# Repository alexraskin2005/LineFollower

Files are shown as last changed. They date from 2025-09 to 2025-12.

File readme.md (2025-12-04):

# LineFollower

Line follower project op HoGent

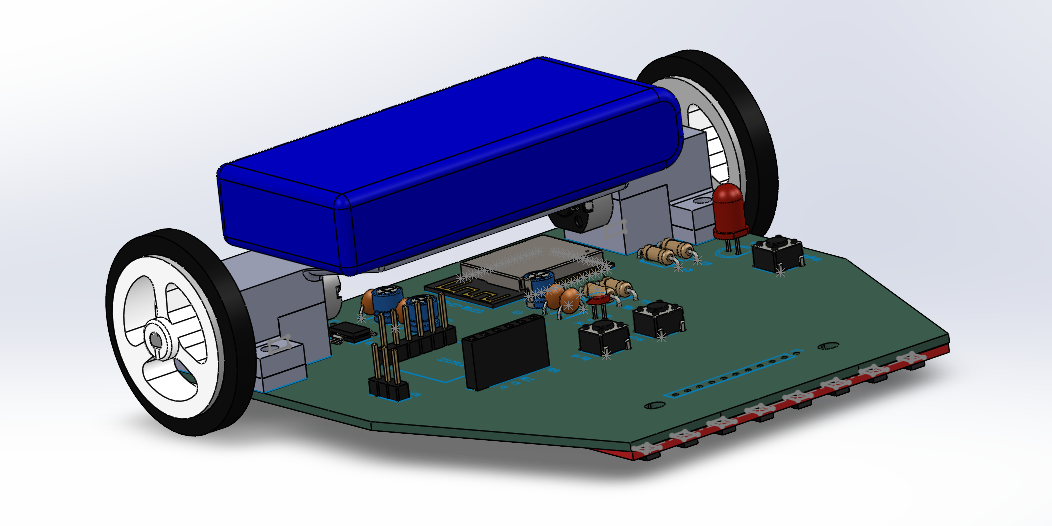
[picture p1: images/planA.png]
A description of my image


## specifications

microcontroller: ESP32

motors: N20 6V 1000RPM

h-bridge: DRV8833

sensors: QTR-8A (fake version)

batteries: lipo 2s 1000mah 20C

wireless communication: ESP32

distance sensor - motors: +-9cm

speed: 0.66 m/s

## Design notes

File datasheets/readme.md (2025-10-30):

# datasheets of the components used in this project

## ESP-WROOM-32:
  datasheet IC:
      https://www.alldatasheet.com/datasheet-pdf/view/1179101/ESPRESSIF/ESP-WROOM-32.html
  
## 8 Channel line tracking sensor:
  geen data sheet maar wel info op product pagina:
      https://nl.aliexpress.com/item/1005007315688221.html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

## GA12-N20 Metal Gear Motor:
  https://www.phippselectronics.com/support/ga12-n20-metal-geared-motor-specifications/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

## DRV8833 motordriver module:
  product page (board): 
      https://nl.aliexpress.com/item/1005006782141292.html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
      
  datasheet IC: 
      https://www.ti.com/lit/ds/symlink/drv8833.pdf?ts=1759987157796
      
  datasheet module:
      https://components101.com/modules/drv8833-dual-h-bridge-motor-driver-module

  ## Turnigy 1000mAh 2S 20C LiPoly Pack:
  product page:
    https://hobbyking.com/en_us/turnigy-1000mah-2s-20c-lipo-pack.html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

  ##  AMS1117:
  https://www.alldatasheet.com/datasheet-pdf/view/49118/ADMOS/AMS1117.html

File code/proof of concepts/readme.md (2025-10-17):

# Proof of Concepts

De proof of concept bestaat uit 1 programma wegens ik verder heb gewerkt op de zelfde fille en vergeten ben apparte filles te maken.
<br />  
<br />
Deze proof of concept heeft de volgende functionaliteit:
* Verbinden via wifi, indien de credentials uit het eeprom niet werken wordt er een configure portal opgezet om deze in te kunnen geven (esp32 in router mode)
* Eenmaal verbonden met wifi kan met linefollwer.local/set?m1= of /set?m2= de pwm output voor de motoren ingesteld worden
* Met linefollwer.local/start of /stop kunnen de motoren gestart en gestopt worden
* Met linefollwer.local/debug kunnen parameters uitgelezen worden, hiermee kunnen de sensor waarden bekeken worden
<br />

<br />
Hiermeer worden de volgende zaken aangetoond:
* De draadloze communicatie werkt
* De motoren kunnen afzonderlijk aangestuurd worden
* De sensoren kunnen uitgelezen worden (hier mee ook te zien dat verschil tussen zwart en wit duidelijk is)
<br />
<br />
  
De elektronische schakelingen van de proof of concepts komt overeen met het elektrisch schema van plan B

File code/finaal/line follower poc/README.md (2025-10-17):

ESP32 WiFi service

What I added

- src/wifi_service.h / src/wifi_service.cpp: a simple WiFi service that:
  - loads/stores Wifi credentials in EEPROM using EEPROMAnything (via PlatformIO lib_deps)
  - attempts to connect to WiFi on startup
  - if connection fails, starts an AP named "ESP32_Config" and serves a minimal HTML form to enter SSID and password
  - saves credentials and restarts
- src/main.cpp updated to initialize the service and print status to Serial
- platformio.ini: added lib_deps = EEPROMAnything
 - src/storage.h: centralized EEPROM storage helper for all project parameters (WiFi credentials start at address 0)

How it works

- Stored credentials are read using the `Storage` helper. WiFi credentials use `STORAGE_WIFI_CRED_ADDR` (0) by default. If SSID is empty the service assumes no credentials are present.
- On first boot, or if connection fails within 15 seconds, the device creates an open AP (password "configureme") and serves a tiny web page at http://192.168.4.1/ where you can enter SSID and password.
- After submitting the form the device saves credentials to EEPROM and restarts.

Assumptions and notes

- Uses Arduino ESP32 core WiFi and WebServer. These are provided by the `espressif32` PlatformIO platform.
- The project cannot be built in this environment (PlatformIO not available here). Build and upload on your machine using PlatformIO in VSCode or the CLI.
- The Storage helper uses `EEPROM.put`/`EEPROM.get` (and `EEPROM.commit`). The `EEPROMAnything` library is declared in `platformio.ini` so PlatformIO will fetch it.

How to build locally (Windows PowerShell)

# Install PlatformIO (if not installed)
# Follow PlatformIO installation instructions for VSCode or CLI: https://platformio.org/install/cli

# From project root:
platformio run
platformio run -t upload

Troubleshooting

- If AP page doesn't load, check Serial output for messages and try connecting to WiFi network named "ESP32_Config".
- The configuration portal runs for 5 minutes; if you miss it, power-cycle the board.

Next improvements

- Use WiFiManager or AsyncWebServer for a more robust captive portal (recommended)
- Encrypt stored password or use Preferences (non-EEPROM) API
- Add captive portal DNS to redirect any URL to the portal

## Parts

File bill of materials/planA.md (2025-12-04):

## bill of materials
<br />

|volgnummer|naam|omschrijving|nieuw/recup|kostprijs/stuk|aantal|subtotaal|
|---|----|---|---|---|---|---|
|1|ESP32-S3-WROOM-1|microcontroller|nieuw|  | 1 | 3.83 |
|2|AMS1117|voltage regulator|nieuw|  | 1 | 1.45 |
|3|DRV8833 module | 2 channel DC motordriver | recup | | 1 |
|4| 8 channel IR line tracking sensor | chinese versie van QTR-8A | recup || 1 | 
|5|ZJ327 3PI 34*7 | rubbere wieltjes voor N20 motors | recup | | 1 |
|6|Turnigy 1000mAh 2S 20C LiPoly Pack| baterij | recup | |1|
|7 | 2-3s LiPoly Charger | lader | recup | |1|
|8| Condensator 10uF | ontkoppeling | recup | | 3 |
|9| Condensator 0u1F | ontkoppeling | recup | | 3 |
|10|weerstand 10k ohm | pullup | recup | | 1 |
|11|weerstand 100 ohm | voorschakel led | recup | | 2 |
|12| led rood (klein) | power led | recup | | 1 |
| 13| FT232RL | usb to ttl | new | | 1 |1.69 |
| 14 | pin header female 6P | pin connector | new | | 1 | 2.46 |
| 15 | led groen | wifi status | recup | | 1
| 16 | push button | start enable en boot| recup ||3

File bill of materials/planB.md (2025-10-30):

## bill of materials
(Mechanische componenten nog niet inclusief)
<br />

|volgnummer|naam|omschrijving|nieuw/recup|kostprijs/stuk|aantal|subtotaal|
|---|----|---|---|---|---|---|
| 1| ESP32-WROOM-32 dev board | microcontroller | nieuw | 0,86 (sale) | 1 | 0,86 |
|2| 8 channel IR line tracking sensor | chinese versie van QTR-8A | nieuw | 2,01 | 1 | 2,01 |
|3| 8 channel IR line tracking sensor | andere fabricant (kon maar 1 per klant bestellen) | nieuw | 1,99 | 1 | 1,99 |
|4|GA12-N20 6VDC 1000RPM | geared motor | nieuw | 3,94 | 2 | 7,88 |
|5|DRV8833 module | 2 channel DC motordriver | nieuw | per 10 verkocht | 10 | 3,24 |
|6|ZJ327 3PI 34*7 | rubbere wieltjes voor N20 motors | nieuw | 1,40 | 2 | 2,80 |
|7|Turnigy 1000mAh 2S 20C LiPoly Pack| baterij | nieuw | 6,04 | 1 | 6,04 |
|8 | 2-3s LiPoly Charger | lader | recup | 0 | 1 | 0 |

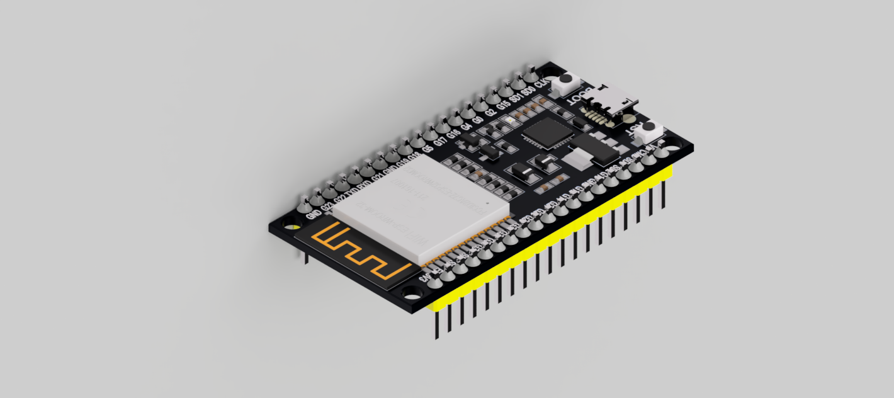
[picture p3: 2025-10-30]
technische tekeningen/mechanisch/parts/esp32-wroom32-devboard/ESP32-WROOM-32_4.png

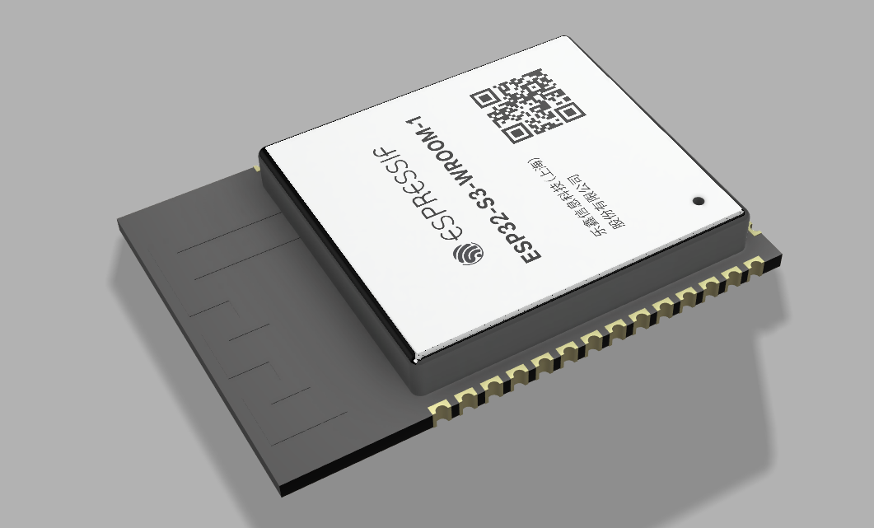
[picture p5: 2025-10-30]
technische tekeningen/mechanisch/parts/esp32-s3-wroom-1/QQ截图20210924173026.png

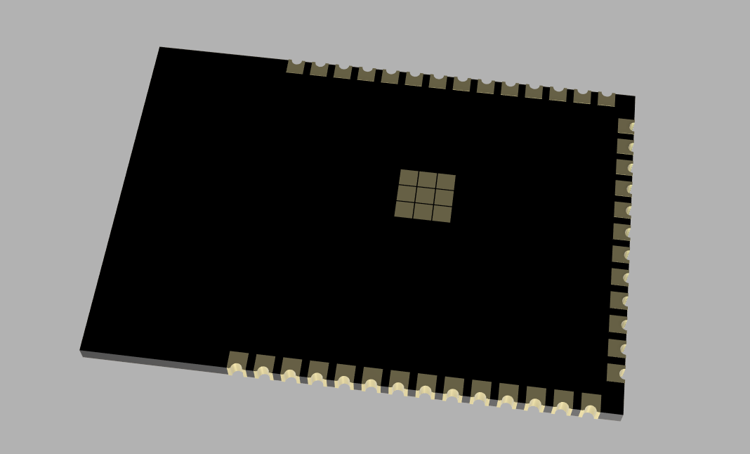
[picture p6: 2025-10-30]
technische tekeningen/mechanisch/parts/esp32-s3-wroom-1/QQ截图20210924175035.png

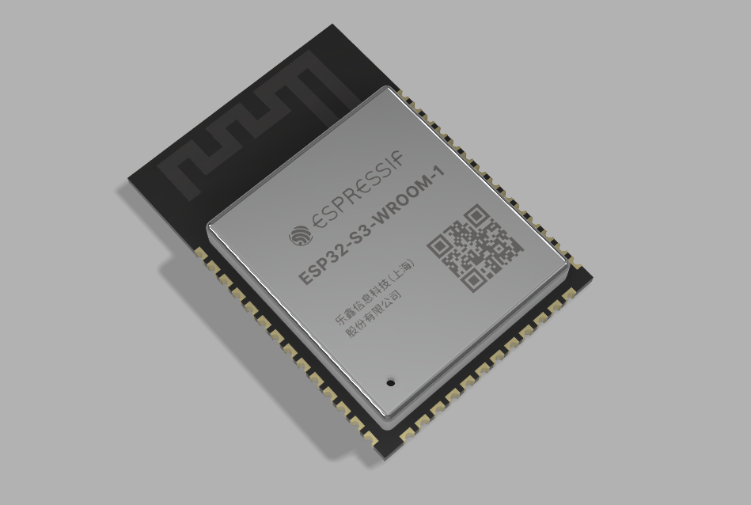
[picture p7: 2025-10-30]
technische tekeningen/mechanisch/parts/esp32-s3-wroom-1/QQ截图20210924200240.png

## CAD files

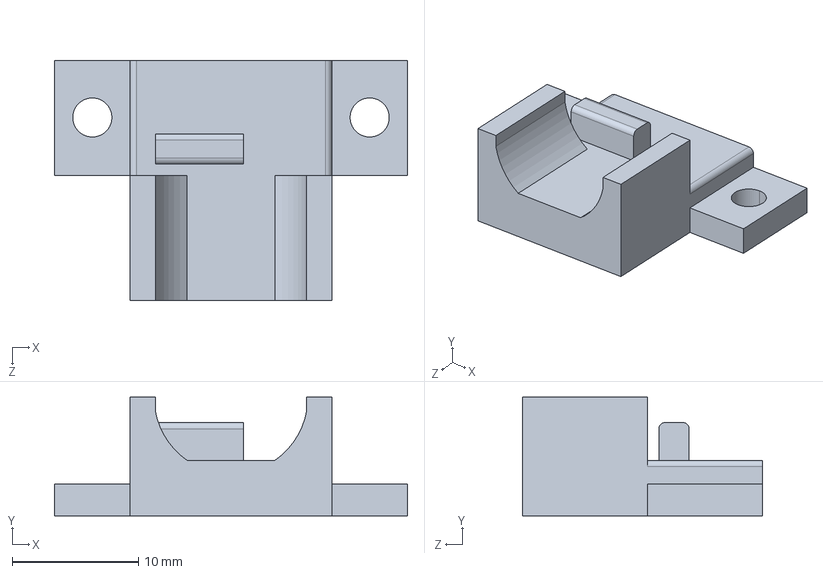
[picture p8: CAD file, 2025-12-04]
technische tekeningen/mechanisch/parts/3D print/n20_holder19_11.STEP
28.0 x 9.40 x 19.0 mm

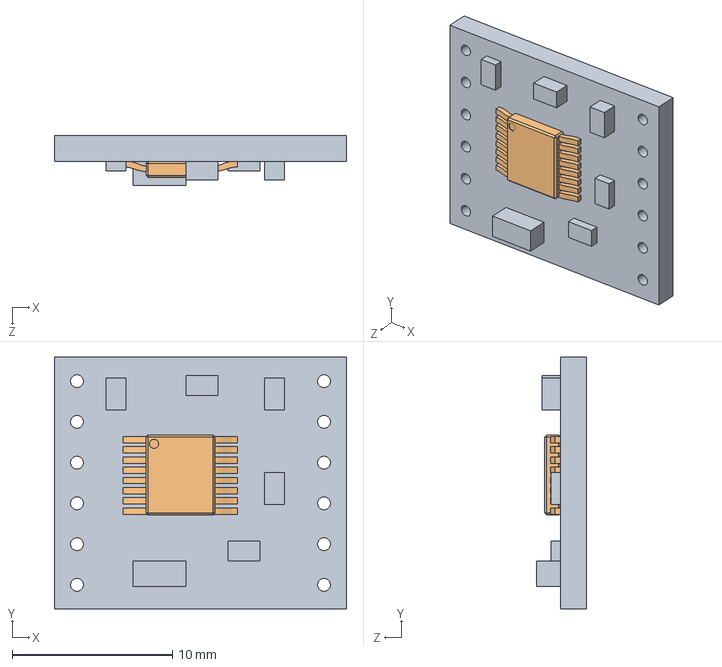
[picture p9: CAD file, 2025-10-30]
technische tekeningen/mechanisch/parts/drv8833-carrier-breakout-board-1/DRV8833.STEP
18.2 x 15.7 x 3.10 mm

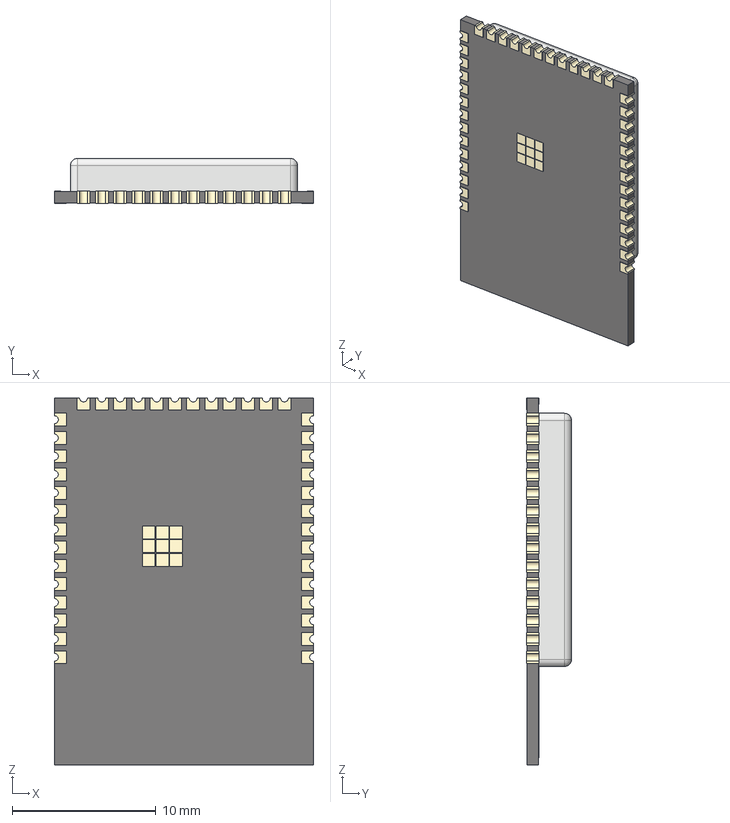
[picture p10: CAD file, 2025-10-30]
technische tekeningen/mechanisch/parts/esp32-s3-wroom-1/ESP32-S3-WROOM.step
18.0 x 3.16 x 25.5 mm
ESP-S3-WROOM_via x 26
ESP32-S3-WROOM_shell
ESP32-S3-WROOM_body
ESP-S3-WROOM_via v3(镜像) x 14

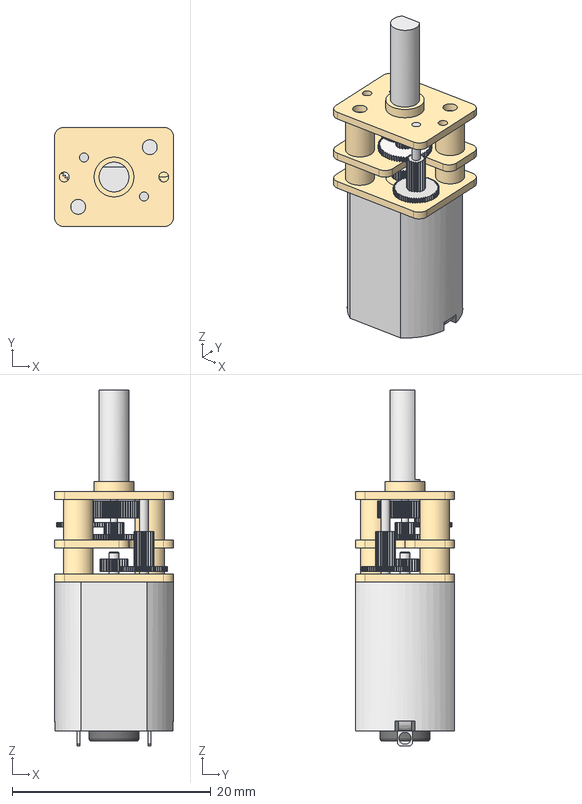
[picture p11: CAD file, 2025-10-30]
technische tekeningen/mechanisch/parts/N20 DC Gear Motor/N20 DC Gear Motor.step
12.0 x 10.0 x 35.8 mm
Gear Box
Shaft
Motor

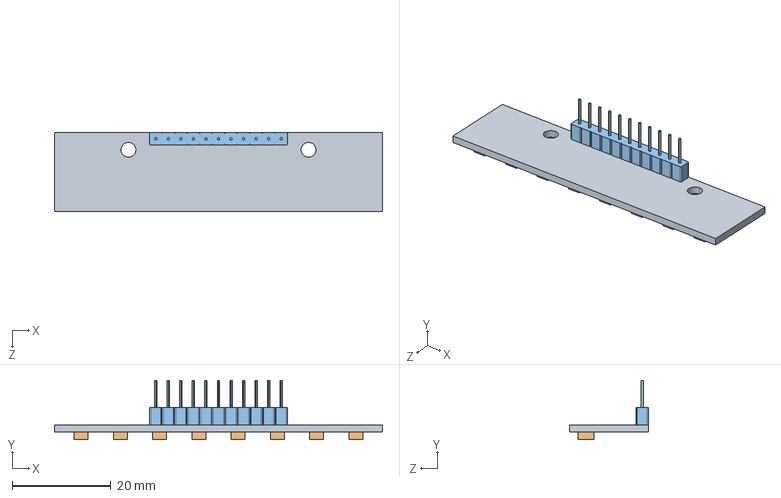
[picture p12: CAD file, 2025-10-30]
technische tekeningen/mechanisch/parts/qtr-8-1.snapshot.2/Qtr-8 IR Array.STEP
66.5 x 12.0 x 16.0 mm

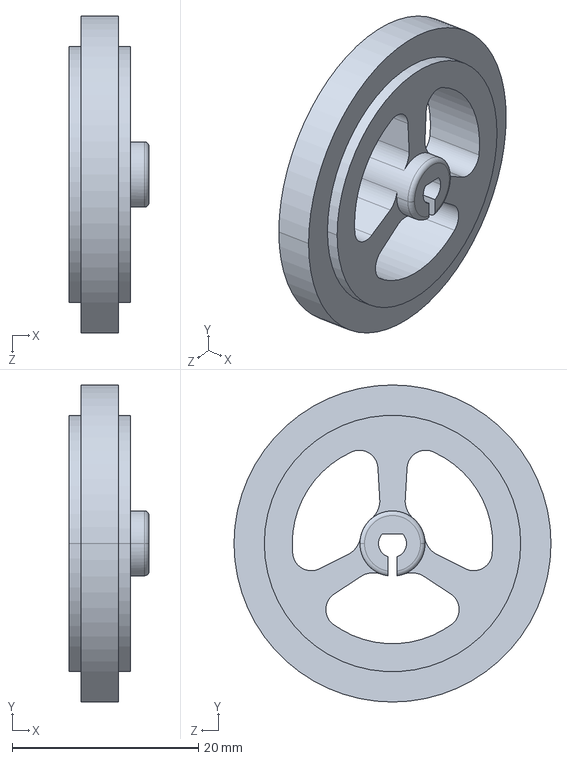
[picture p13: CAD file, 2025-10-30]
technische tekeningen/mechanisch/parts/wheel-34mm/Wheel 34 mm.STEP
8.60 x 34.0 x 34.0 mm

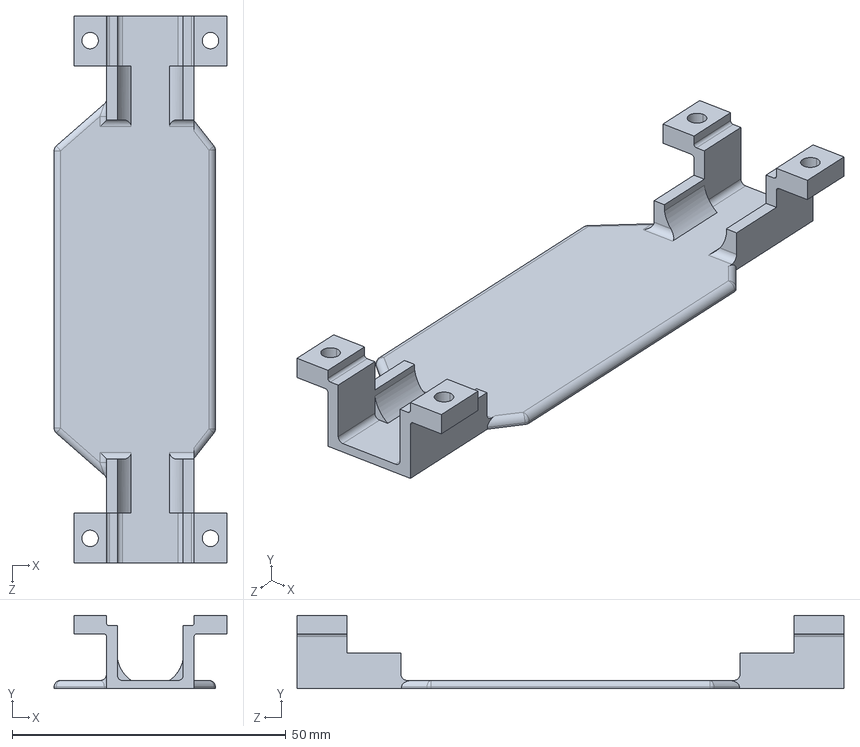
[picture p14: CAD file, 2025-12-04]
technische tekeningen/mechanisch/parts/3D print/batteryholder19_11.STEP
31.6 x 13.4 x 100.0 mm

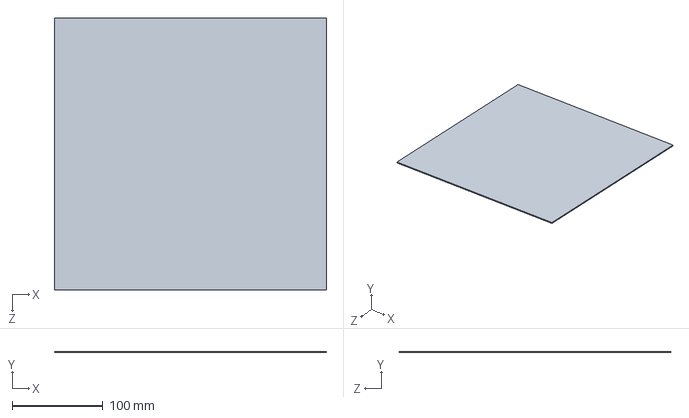
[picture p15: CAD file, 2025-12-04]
technische tekeningen/mechanisch/parts/base.SLDPRT
300.0 x 1.60 x 300.0 mm

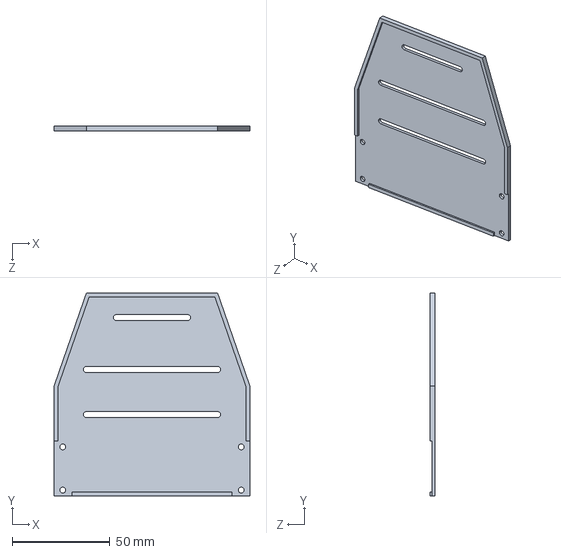
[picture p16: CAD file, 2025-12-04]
technische tekeningen/mechanisch/parts/3D print/base19_11.STEP
100.0 x 103.5 x 2.60 mm

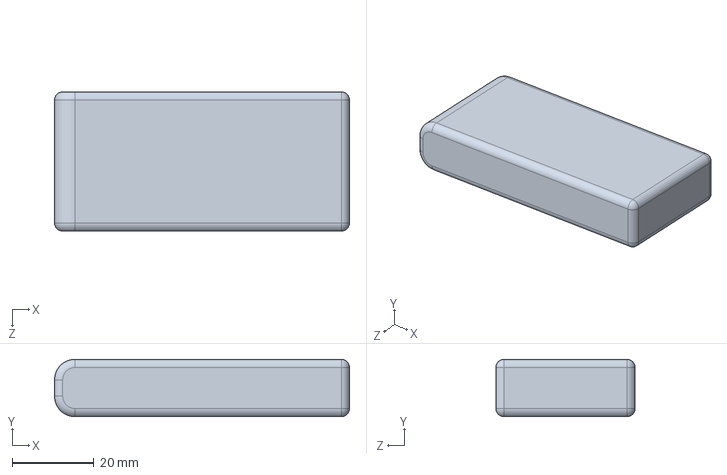
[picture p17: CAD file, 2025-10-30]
technische tekeningen/mechanisch/parts/Turnigy_1000mAh_2S_20C_LiPoly_Pack.SLDPRT
72.0 x 14.0 x 34.0 mm

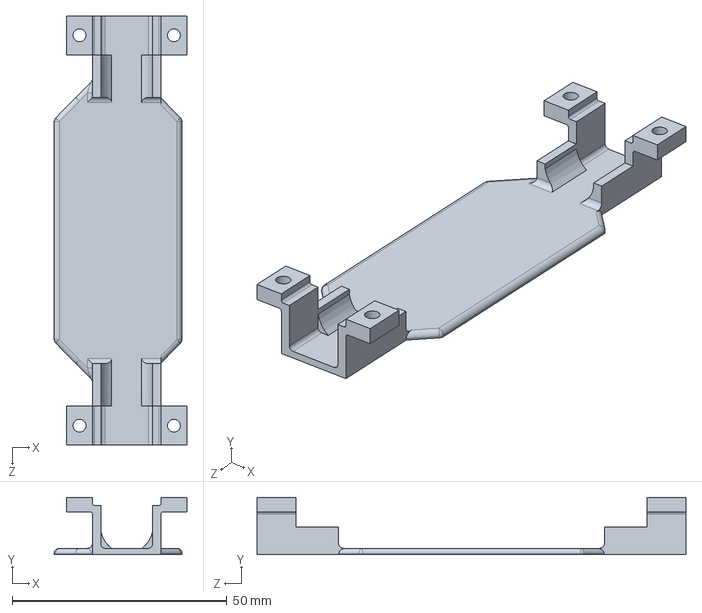
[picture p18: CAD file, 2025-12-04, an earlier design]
technische tekeningen/mechanisch/parts/batteryholder - Copy.SLDPRT
30.9 x 13.4 x 100.0 mm

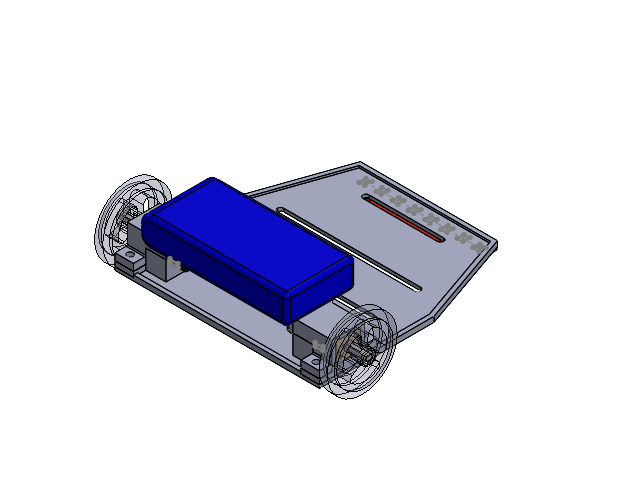
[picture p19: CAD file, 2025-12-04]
technische tekeningen/mechanisch/planB.SLDASM
Turnigy_1000mAh_2S_20C_LiPoly_Pack
Gear Box.step x 2
Shaft.step x 2
Motor.step x 2
Roda 34 mm x 2
Qtr-8 IR Array
n20_holder x 2
base2
batteryholder

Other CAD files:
technische tekeningen/mechanisch/parts/n20_holder.SLDPRT
technische tekeningen/mechanisch/parts/wheel-34mm/Roda 34 mm.STEP
technische tekeningen/mechanisch/parts/batteryholder.SLDPRT
technische tekeningen/mechanisch/parts/base2.SLDPRT
technische tekeningen/mechanisch/parts/3D print/base19_11.STL
technische tekeningen/mechanisch/parts/3D print/batteryholder19_11.STL
technische tekeningen/mechanisch/parts/3D print/n20_holder19_11.STL
technische tekeningen/mechanisch/parts/N20 DC Gear Motor/N20 DC Gear Motor.f3d
technische tekeningen/mechanisch/parts/drv8833-carrier-breakout-board-1/DRV8833.IGS
technische tekeningen/mechanisch/parts/drv8833-carrier-breakout-board-1/DRV8833.SLDPRT
technische tekeningen/mechanisch/parts/qtr-8-1.snapshot.2/Qtr-8 IR Array.SLDPRT
technische tekeningen/mechanisch/parts/qtr-8-1.snapshot.2/Qtr-8 IR Array.STL
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

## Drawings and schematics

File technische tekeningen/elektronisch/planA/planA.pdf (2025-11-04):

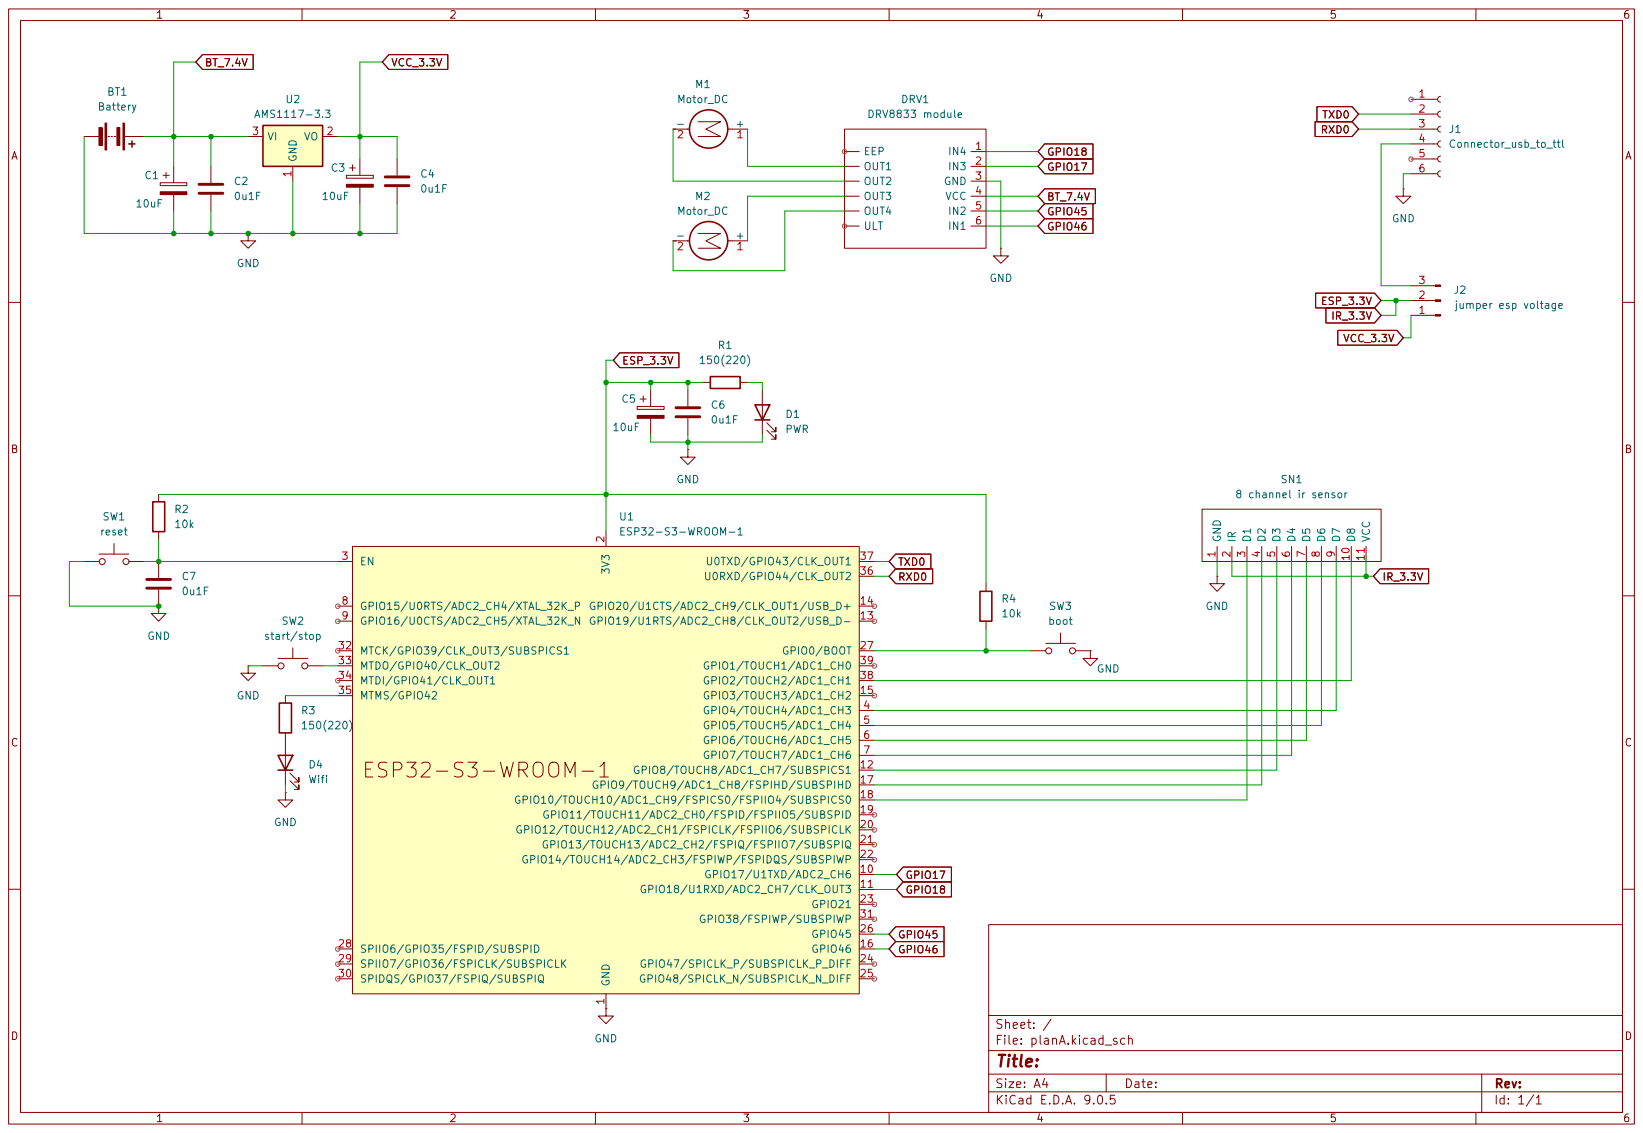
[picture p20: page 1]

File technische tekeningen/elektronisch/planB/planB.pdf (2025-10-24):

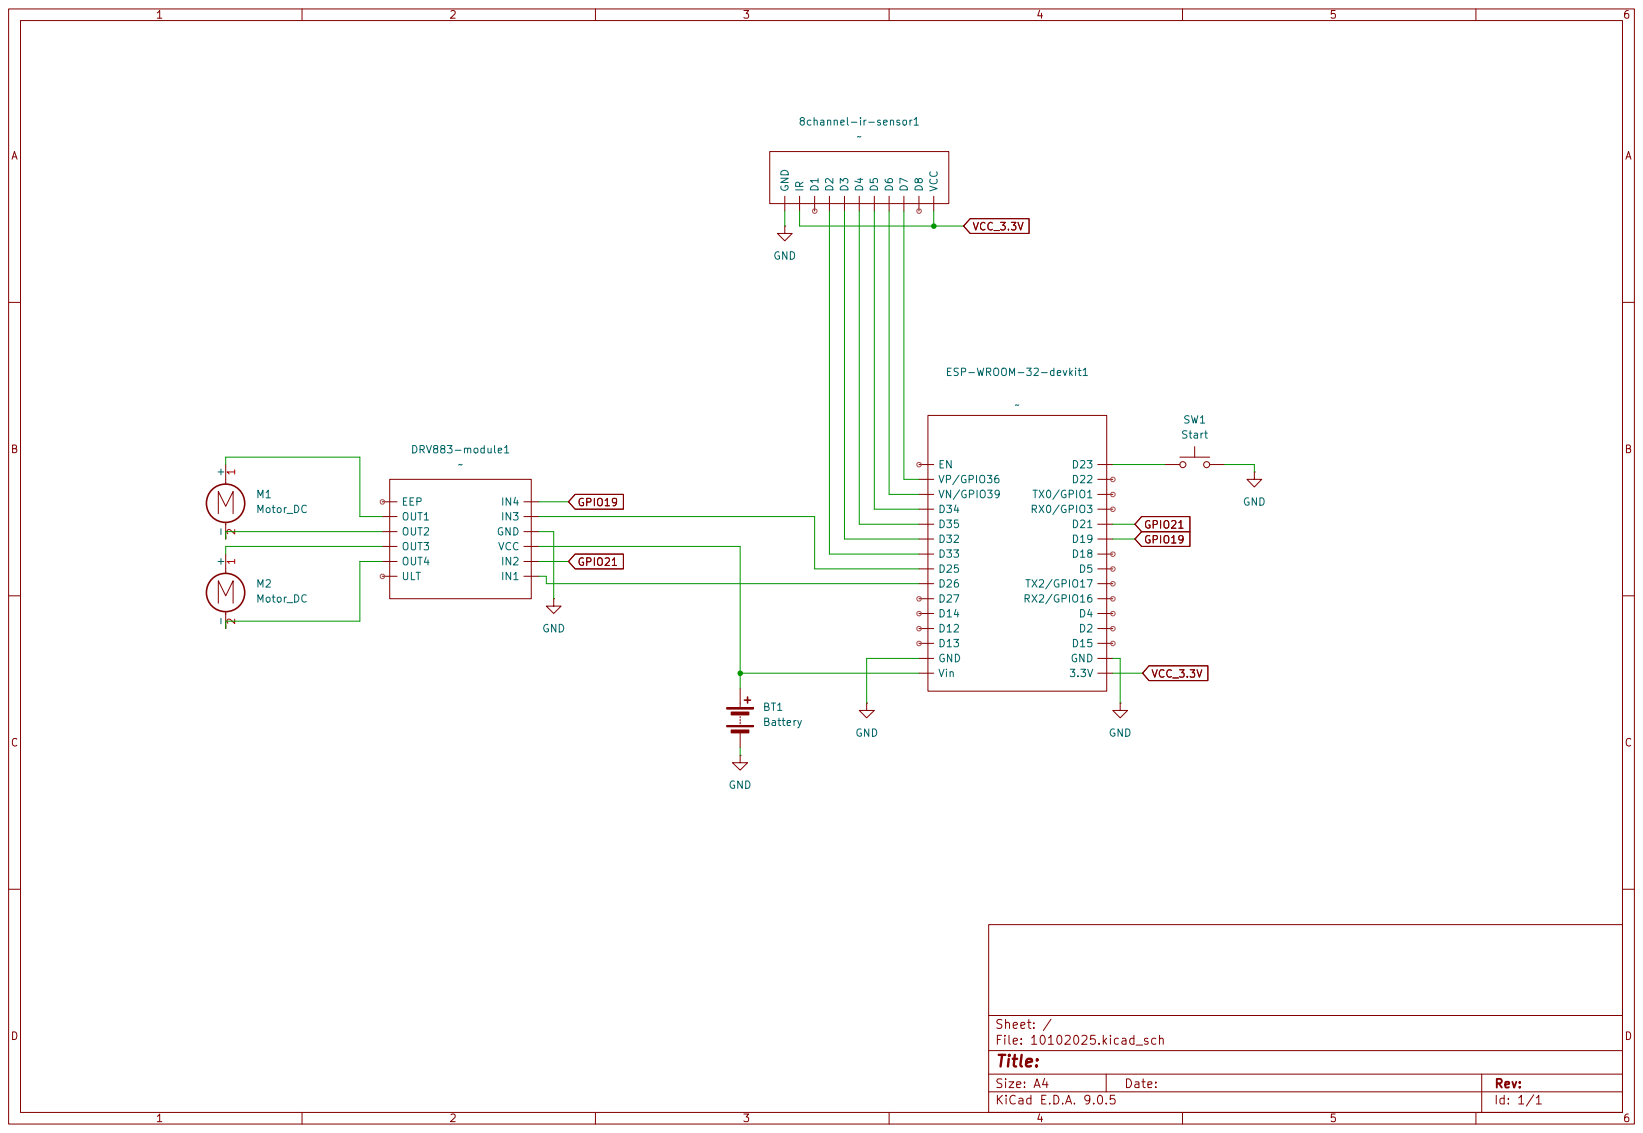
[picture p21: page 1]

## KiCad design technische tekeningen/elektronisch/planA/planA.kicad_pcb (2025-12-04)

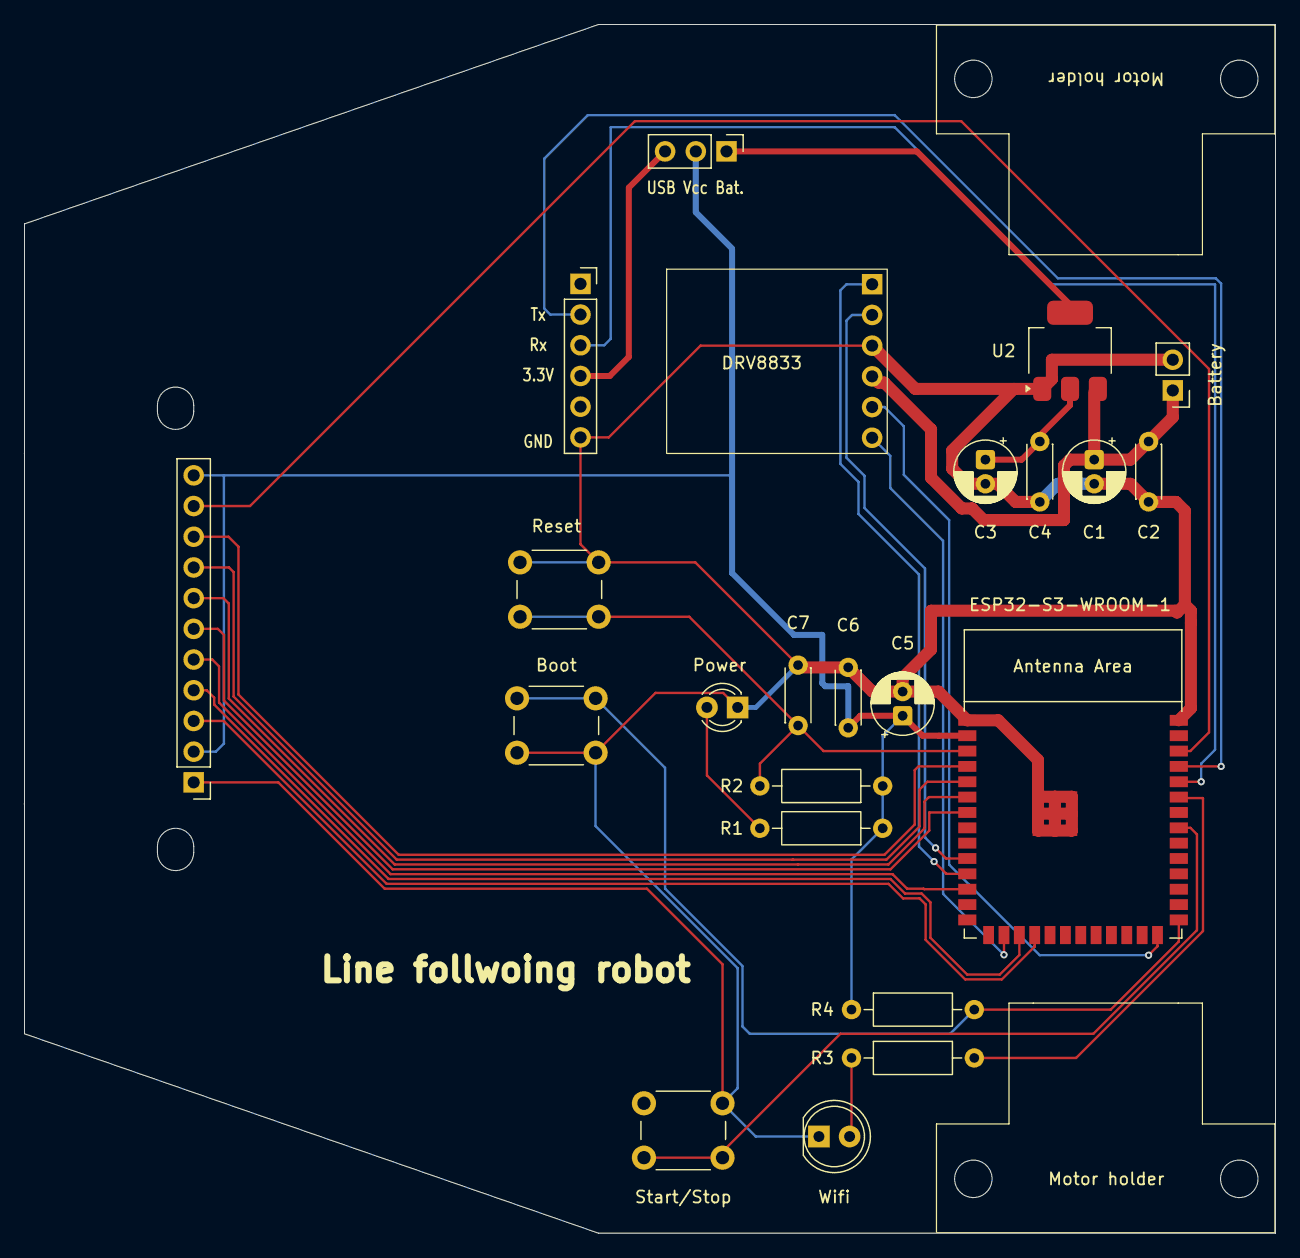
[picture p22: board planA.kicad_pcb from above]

Board: 2 copper layers, 103.5 x 100.0 mm, 25 parts (0 on the bottom side), 25 nets.

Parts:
Battery: Battery; PinHeader_1x02_P2.54mm_Vertical
Boot: boot; SW_PUSH_6mm_H4.3mm
C1, C3, C5: 10uF; CP_Radial_D5.0mm_P2.00mm
C2, C4, C6, C7: 0u1F; C_Disc_D4.3mm_W1.9mm_P5.00mm
DRV8833: DRV8833 module; DRV8833_Module_1x06_P2,54mm
J1: Connector_usb_to_ttl; PinSocket_1x06_P2.54mm_Vertical
M1, M2: Motor_DC; motor holder
Power: PWR; LED_D3.0mm
R1, R3: 150(220); R_Axial_DIN0207_L6.3mm_D2.5mm_P10.16mm_Horizontal
R2, R4: 10k; R_Axial_DIN0207_L6.3mm_D2.5mm_P10.16mm_Horizontal
Reset: reset; SW_PUSH_6mm_H4.3mm
SN1: 8 channel ir sensor; 8channel_ir_sensor_1x11_P2.54mm
Start/Stop: start/stop; SW_PUSH_6mm_H4.3mm
U1: ESP32-S3-WROOM-1
U2: AMS1117-3.3; SOT-223-3_TabPin2
USB Vcc Bat.: jumper esp voltage; PinHeader_1x03_P2.54mm_Vertical
Wifi: Wifi; LED_D5.0mm

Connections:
BT_7.4V: Battery.1 (+), C1.1, C2.1, DRV8833.4 (VCC), U2.3 (VI)
ESP_3.3V: C5.1, C6.1, R1.1, R2.1, R4.1, SN1.2 (IR), SN1.11 (VCC), U1.2 (3V3), USB Vcc Bat..2
GND: Battery.2 (-), Boot.2, C1.2, C2.2, C3.2, C4.2, C5.2, C6.2, C7.2, DRV8833.3 (GND), J1.6 (GND), Power.1 (K), Reset.1, SN1.1 (GND), Start/Stop.1, U1.1 (GND), U1.40 (GND), U1.41 (GND), U2.1 (GND), Wifi.1 (K)
GPIO17: DRV8833.2 (IN3), U1.10 (GPIO17/U1TXD/ADC2_CH6)
GPIO18: DRV8833.1 (IN4), U1.11 (GPIO18/U1RXD/ADC2_CH7/CLK_OUT3)
GPIO45: DRV8833.5 (IN2), U1.26 (GPIO45)
GPIO46: DRV8833.6 (IN1), U1.16 (GPIO46)
unnamed: Power.2 (A), R1.2
unnamed: R3.1, Wifi.2 (A)
unnamed: J1.4 (VCC), USB Vcc Bat..3
unnamed: SN1.3 (D1), U1.18 (GPIO10/TOUCH10/ADC1_CH9/FSPICS0/FSPIIO4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)
unnamed: SN1.4 (D2), U1.17 (GPIO9/TOUCH9/ADC1_CH8/FSPIHD/SUBSPIHD)
unnamed: SN1.5 (D3), U1.12 (GPIO8/TOUCH8/ADC1_CH7/SUBSPICS1)
unnamed: SN1.6 (D4), U1.7 (GPIO7/TOUCH7/ADC1_CH6)
unnamed: SN1.7 (D5), U1.6 (GPIO6/TOUCH6/ADC1_CH5)
unnamed: SN1.8 (D6), U1.5 (GPIO5/TOUCH5/ADC1_CH4)
unnamed: SN1.9 (D7), U1.4 (GPIO4/TOUCH4/ADC1_CH3)
unnamed: SN1.10 (D8), U1.38 (GPIO2/TOUCH2/ADC1_CH1)
unnamed: C7.1, R2.2, Reset.2, U1.3 (EN)
unnamed: Boot.1, R4.2, U1.27 (GPIO0/BOOT)
unnamed: Start/Stop.2, U1.33 (MTDO/GPIO40/CLK_OUT2)
unnamed: R3.2, U1.35 (MTMS/GPIO42)
RXD0: J1.3 (TX), U1.36 (U0RXD/GPIO44/CLK_OUT2)
TXD0: J1.2 (RX), U1.37 (U0TXD/GPIO43/CLK_OUT1)
VCC_3.3V: C3.1, C4.1, U2.2 (VO), USB Vcc Bat..1

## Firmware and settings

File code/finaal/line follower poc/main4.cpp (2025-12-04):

#include <Arduino.h>
#include "EEPROMAnything.h"
#include <WiFi.h>
#include <WebServer.h>
#include <DNSServer.h>
#include <ESPmDNS.h>
#include <ArduinoJson.h>

// control loop timing
unsigned long previous = 0;
unsigned long calculationTime = 0;
unsigned long calculationTimeSum = 0;
int cycleCount = 0;
// data streaming
int cyclesSinceLastSend = 0;
int cyclesPerSend = 4; // send data every n cycles

unsigned long lastSeenLineTime = 1000; // time when line was last seen

bool running = false;
int forwardSpeed = 0;
// PID
float error = 0, linePosition = 0, correction = 0, scale = 1.0f;

// motors
double m1_pwm_fwd = 0, m1_pwm_bwd = 0, m2_pwm_fwd = 0, m2_pwm_bwd = 0;
double m1 = 0, m2 = 0, m1_raw = 0, m2_raw = 0; // motor PWM values and speed commands
bool motorsEnabled = false;

bool ledWifiStatus = false;
int pinWifiStatus = 3;

// sensors
float mappedSensors[8] = {}; // mapped sensor readings 0..1000 (0 white - 1000 black)
int sensors[8];               // raw readings 0..4095
int sensorPins[8] = {0, 33, 32, 35, 34, 39, 36, 0}; // 0 means not present

struct param_t {
  unsigned long cycleTime = 2000; // default microseconds between cycles (keep consistent with usage)
  char ssid[32] = "";
  char password[64] = "";
  int defaultSpeed = 300; // default motor speed
  int maxSpeed = 800;     // maximum allowed motor speed
  int blackValues[8] = {0, 0, 0, 0, 0, 0, 0, 0};
  int whiteValues[8] = {4095, 4095, 4095, 4095, 4095, 4095, 4095, 4095};
  double kp = 1.5;
  double ki = 0.0;
  double kd = 0.0;
  int maxTimeWithoutLine = 2000; // ms
  int maxTimeDriveFullPower = 2000; // ms
} params;

/// WiFi and servers
WebServer server(80);
DNSServer dnsServer;
WiFiServer serverTCP(1234);
WiFiClient client;

// PWM channels for ESP32 ledc (one per motor direction)
const int PWM_CHANNEL_M1_FWD = 0;
const int PWM_CHANNEL_M1_BWD = 1;
const int PWM_CHANNEL_M2_FWD = 2;
const int PWM_CHANNEL_M2_BWD = 3;
const int PWM_FREQ = 20000; // 20 kHz
const int PWM_RES = 8;      // 8-bit resolution (0..255)

bool tryConnectWithParams(unsigned long timeoutMs = 15000) { // try connecting with saved info
  if (strlen(params.ssid) == 0) return false;

  WiFi.mode(WIFI_STA);
  Serial.print("Connecting to "); Serial.println(params.ssid);
  Serial.print("With password: "); Serial.println(params.password);
  WiFi.begin(params.ssid, params.password);

  unsigned long start = millis();
  while (millis() - start < timeoutMs) {
    if (WiFi.status() == WL_CONNECTED) {
      Serial.print("Connected to ");
      Serial.print(params.ssid);
      Serial.print(" with IP: ");
      Serial.println(WiFi.localIP());
      return true;
    }
    delay(200);
  }
  return false;
}

void startConfigPortal(unsigned long portalTimeoutMs = 5 * 60 * 1000) { // start configuration portal to set wifi credentials
  const char *apName = "lineFollower_Wifi_Config";
  const char *apPass = "configureme";

  // Configure AP IP and start AP
  IPAddress apIP(192, 168, 4, 1);
  IPAddress apGateway(192, 168, 4, 1);
  IPAddress apSubnet(255, 255, 255, 0);

  WiFi.mode(WIFI_AP);
  WiFi.softAPConfig(apIP, apGateway, apSubnet);
  WiFi.softAP(apName, apPass);

  const byte DNS_PORT = 53;
  dnsServer.start(DNS_PORT, "*", apIP);

  server.on("/", [&]() {
    String page = "<html><body>"
                  "<h2>LineFollower WiFi Setup</h2>"
                  "<form action=\"/save\" method=\"POST\">"
                  "SSID:<br><input type=\"text\" name=\"ssid\" value=\"" + String(params.ssid) + "\"><br>"
                                                                                               "Password:<br><input type=\"password\" name=\"pwd\"><br><br>"
                                                                                               "<input type=\"submit\" value=\"Save\">"
                                                                                               "</form></body></html>";
    server.send(200, "text/html", page);
  });

  server.on("/save", HTTP_POST, [&]() {
    if (server.hasArg("ssid") && server.hasArg("pwd")) {
      String ss = server.arg("ssid");
      String pw = server.arg("pwd");
      ss.toCharArray(params.ssid, sizeof(params.ssid));
      pw.toCharArray(params.password, sizeof(params.password));
      Serial.println("Saving new credentials:");
      Serial.print("SSID: ");
      Serial.println(params.ssid);
      Serial.print("Password: ");
      Serial.println(params.password);
      EEPROM_writeAnything(0, params);
      server.send(200, "text/html", "Saved credentials. Device will restart and attempt to connect.");
      delay(1000);
      ESP.restart();
    } else {
      server.send(400, "text/plain", "Missing fields");
    }
  });

  server.onNotFound([&]() {
    server.send(404, "text/plain", "Not found");
  });

  server.begin();

  unsigned long started = millis();
  while (millis() - started < portalTimeoutMs) {
    dnsServer.processNextRequest();
    server.handleClient();
    delay(50);
    digitalWrite(pinWifiStatus, !digitalRead(pinWifiStatus)); // Blink WiFi status LED
  }

  server.stop();
  dnsServer.stop();
  WiFi.softAPdisconnect(true);
}

void startWifi() {
  if (tryConnectWithParams()) {
    return;
  }
  Serial.println("Connection failed, starting config portal...");
  startConfigPortal();
}

void dataStreaming() {
  if (!client || !client.connected()) {
    client = serverTCP.available(); // Accept new client
  }

  cyclesSinceLastSend++;
  if (client && client.connected() && cyclesSinceLastSend >= cyclesPerSend) {
    cyclesSinceLastSend = 0;

    // Build compact JSON manually (ok) -- can be replaced with StaticJsonDocument for safety
    String output = "{";
    output += "\"timeStamp\":" + String(millis()) + ",";
    output += "\"ssid\":\"" + String(params.ssid) + "\",";
    output += "\"cycleTime\":" + String(params.cycleTime) + ",";
    output += "\"calculationTime\":" + String(calculationTime) + ",";
    output += "\"running\":" + String(running ? 1 : 0) + ",";
    output += "\"motorsEnabled\":" + String(motorsEnabled ? 1 : 0) + ",";
    output += "\"kp\":" + String(params.kp) + ",";
    output += "\"ki\":" + String(params.ki) + ",";
    output += "\"kd\":" + String(params.kd) + ",";
    output += "\"linePosition\":" + String(linePosition) + ",";
    output += "\"error\":" + String(error) + ",";
    output += "\"correction\":" + String(correction) + ",";
    output += "\"motor1\":" + String(m1) + ",";
    output += "\"motor2\":" + String(m2) + ",";
    output += "\"defaultSpeed\":" + String(params.defaultSpeed) + ",";
    output += "\"maxSpeed\":" + String(params.maxSpeed) + ",";
    output += "\"maxTimeWithoutLine\":" + String(params.maxTimeWithoutLine) + ",";
    output += "\"maxTimeDriveFullPower\":" + String(params.maxTimeDriveFullPower) + ",";

    output += "\"rawSensors\":[";
    for (int i = 0; i < 8; i++) {
      output += String(sensors[i]);
      if (i < 7) output += ",";
    }
    output += "],";

    output += "\"sensors\":[";
    for (int i = 0; i < 8; i++) {
      output += String(mappedSensors[i], 2);
      if (i < 7) output += ",";
    }
    output += "],";

    output += "\"blackValues\":[";
    for (int i = 0; i < 8; i++) {
      output += String(params.blackValues[i]);
      if (i < 7) output += ",";
    }
    output += "],";

    output += "\"whiteValues\":[";
    for (int i = 0; i < 8; i++) {
      output += String(params.whiteValues[i]);
      if (i < 7) output += ",";
    }
    output += "]";

    output += "}";

    client.println(output);
  }
}

void startRunTimeServer() {
  // start/stop
  server.on("/start", HTTP_ANY, []() {
    running = true;
    Serial.println("Control loop started via /start");
    server.send(200, "text/plain", "Started");
  });

  server.on("/stop", HTTP_ANY, []() {
    running = false;
    Serial.println("Control loop stopped via /stop");
    server.send(200, "text/plain", "Stopped");
  });

  server.on("/enable", HTTP_ANY, []() {
    motorsEnabled = true;
    Serial.println("motors enabled");
    server.send(200, "text/plain", "motors enabled");
  });

  server.on("/disable", HTTP_ANY, []() {
    motorsEnabled = false;
    Serial.println("motors disabled");
    server.send(200, "text/plain", "motors disabled");
  });

  // set parameters
  server.on("/set", HTTP_ANY, []() {
    bool changed = false;
    if (server.hasArg("cycleTime")) {
      params.cycleTime = (unsigned long)atol(server.arg("cycleTime").c_str());
      Serial.print("Set cycleTime to ");
      Serial.println(params.cycleTime);
      changed = true;
    }
    if (server.hasArg("ssid")) {
      server.arg("ssid").toCharArray(params.ssid, sizeof(params.ssid));
      Serial.print("Set SSID to ");
      Serial.println(params.ssid);
      changed = true;
    }
    if (server.hasArg("password")) {
      server.arg("password").toCharArray(params.password, sizeof(params.password));
      Serial.print("Set password to ");
      Serial.println(params.password);
      changed = true;
    }
    if (server.hasArg("defaultSpeed")) {
      params.defaultSpeed = atoi(server.arg("defaultSpeed").c_str());
      Serial.print("Set defaultSpeed to ");
      Serial.println(params.defaultSpeed);
      changed = true;
    }
    if (server.hasArg("maxSpeed")) {
      params.maxSpeed = atoi(server.arg("maxSpeed").c_str());
      Serial.print("Set maxSpeed to ");
      Serial.println(params.maxSpeed);
      changed = true;
    }
    if (server.hasArg("kp")) {
      params.kp = atof(server.arg("kp").c_str());
      Serial.print("Set kp to ");
      Serial.println(params.kp);
      changed = true;
    }
    if (server.hasArg("ki")) {
      params.ki = atof(server.arg("ki").c_str());
      Serial.print("Set ki to ");
      Serial.println(params.ki);
      changed = true;
    }
    if (server.hasArg("kd")) {
      params.kd = atof(server.arg("kd").c_str());
      Serial.print("Set kd to ");
      Serial.println(params.kd);
      changed = true;
    }
    if (server.hasArg("maxTimeDriveFullPower")) {
      params.maxTimeDriveFullPower = atoi(server.arg("maxTimeDriveFullPower").c_str());
      Serial.print("maxTimeDriveFullPower set to ");
      Serial.println(params.maxTimeDriveFullPower);
      changed = true;
    }
    if (server.hasArg("maxTimeWithoutLine")) {
      params.maxTimeWithoutLine = atoi(server.arg("maxTimeWithoutLine").c_str());
      Serial.print("maxTimeWithoutLine set to ");
      Serial.println(params.maxTimeWithoutLine);
      changed = true;
    }

    if (changed) {
      EEPROM_writeAnything(0, params);
      server.send(200, "text/plain", "Parameters updated and saved");
    } else {
      server.send(400, "text/plain", "No valid parameters provided");
    }
  });

  // calibration
  server.on("/calibrate/white", HTTP_ANY, []() {
    for (int i = 0; i < 8; ++i) {
      if (sensorPins[i] != 0) params.whiteValues[i] = analogRead(sensorPins[i]);
      else params.whiteValues[i] = 0;
    }
    EEPROM_writeAnything(0, params);
    Serial.println("Calibration: saved WHITE values");
    server.send(200, "text/plain", "White calibration saved");
  });

  server.on("/calibrate/black", HTTP_ANY, []() {
    for (int i = 0; i < 8; ++i) {
      if (sensorPins[i] != 0) params.blackValues[i] = analogRead(sensorPins[i]);
      else params.blackValues[i] = 4095;
    }
    EEPROM_writeAnything(0, params);
    Serial.println("Calibration: saved BLACK values");
    server.send(200, "text/plain", "Black calibration saved");
  });

  server.on("/calibrate/reset", HTTP_ANY, []() {
    for (int i = 0; i < 8; ++i) {
      params.whiteValues[i] = 0;
      params.blackValues[i] = 4095;
    }
    EEPROM_writeAnything(0, params);
    Serial.println("Calibration: reset to defaults");
    server.send(200, "text/plain", "Calibration reset to defaults");
  });

  server.begin();
  Serial.println("Runtime HTTP server started on port 80");
}

// Return true if ALL sensors indicate black (i.e., mapped reading >= threshold)
bool checkAllBlack(const float readings[8], float threshold = 800.0f) {
  for (int i = 1; i < 7; ++i) {
    // *** SAFETY FIX: guard against NaN/Inf
    if (!isfinite(readings[i]) || readings[i] < 0.0f) return false;
    if (readings[i] < threshold) { // if any reading below threshold -> not all black
      return false;
    }
  }
  return true;
}

// Return true if ALL sensors indicate white (i.e., mapped reading <= threshold)
bool checkAllWhite(const float readings[8], float threshold = 200.0f) {
  for (int i = 0; i < 8; ++i) {
    // *** SAFETY FIX: guard against NaN/Inf
    if (!isfinite(readings[i]) || readings[i] < 0.0f) return false;
    if (readings[i] > threshold) { // if any reading above threshold -> not all white
      return false;
    }
  }
  return true;
}

// Determine line position from raw sensor readings (as in original)
// returns position in mm relative to center (approx)
float getLinePosition(int readings[8]) {
  // *** SAFETY FIX: validate input range and clamp
  for (int i = 0; i < 8; ++i) {
    if (readings[i] < 0) readings[i] = 0;
    if (readings[i] > 10000) readings[i] = 10000; // very large spike protection
  }

  int index = 1;
  for (int i = 2; i <= 6; i++) {
    if (readings[i] > readings[index]) index = i;
  }
  if (index == 1) index = 2;
  else if (index == 6) index = 5;

  long sZero = readings[index];
  long sMinusOne = readings[index - 1];
  long sPlusOne = readings[index + 1];

  float b = ((float)(sPlusOne - sMinusOne)) / 2.0f;
  float a = sPlusOne - b - sZero;

  // handle degenerate a
  float position = 0.0f;
  if (fabs(a) > 1e-6f) {
    position = -b / (2.0f * a);
  } else {
    position = 0.0f;
  }

  // *** SAFETY FIX: check NaN/Inf and clamp
  if (!isfinite(position)) position = 0.0f;

  position += index - 3.5f;
  position *= 8.0f; // sensor distance in mm

  // *** SAFETY FIX: hard clamp
  position = constrain(position, -33.0f, 33.0f);

  return position;
}

// Improved PID compute with safe first-run handling
float pidCompute(float error, double kp, double ki, double kd) {
  static double integral = 0.0;
  static float lastError = 0.0f;
  static unsigned long lastTime = 0;
  static bool firstRun = true;

  unsigned long now = millis();
  if (firstRun) {
    lastTime = now;
    lastError = error;
    firstRun = false;
    return 0.0f; // no correction first iteration
  }

  float dt = (now - lastTime) / 1000.0f;
  if (dt <= 0.0f) dt = 1e-3f; // guard
  lastTime = now;

  // *** SAFETY FIX: guard large dt (e.g. after long blocking ops)
  if (dt > 1.0f) dt = 1.0f;

  // Handle NaN/Inf error
  if (!isfinite(error)) error = 0.0f;

  integral += error * dt;

  // *** SAFETY FIX: anti-windup (smaller clamp to be conservative)
  const double INTEGRAL_MAX = 5000.0;
  if (integral > INTEGRAL_MAX) integral = INTEGRAL_MAX;
  if (integral < -INTEGRAL_MAX) integral = -INTEGRAL_MAX;

  float derivative = (error - lastError) / dt;
  lastError = error;

  double out = kp * error + ki * integral + kd * derivative;

  // remove nan/inf
  if (!isfinite(out)) out = 0.0;

  // *** SAFETY FIX: clamp PID output to avoid runaway values
  out = constrain(out, -2000.0, 2000.0);

  return (float)out;
}

// Setup function
void setup() {
  Serial.begin(9600);
  Serial.println("Starting...");

  // Initialize PWM channels for ESP32 (recommended approach)
  ledcSetup(PWM_CHANNEL_M1_FWD, PWM_FREQ, PWM_RES);
  ledcSetup(PWM_CHANNEL_M1_BWD, PWM_FREQ, PWM_RES);
  ledcSetup(PWM_CHANNEL_M2_FWD, PWM_FREQ, PWM_RES);
  ledcSetup(PWM_CHANNEL_M2_BWD, PWM_FREQ, PWM_RES);

  // Attach channels to pins
  ledcAttachPin(25, PWM_CHANNEL_M1_FWD);
  ledcAttachPin(26, PWM_CHANNEL_M1_BWD);
  ledcAttachPin(27, PWM_CHANNEL_M2_FWD);
  ledcAttachPin(14, PWM_CHANNEL_M2_BWD);

  // Ensure EEPROM initialized before reading
  EEPROM.begin(512);
  EEPROM_readAnything(0, params);

  // Configure sensor pins as inputs
  for (int i = 0; i < 8; ++i) {
    if (sensorPins[i] != 0) pinMode(sensorPins[i], INPUT);
  }
  pinMode(pinWifiStatus, OUTPUT);

  startWifi();
  delay(1000);
  if (WiFi.status() == WL_CONNECTED) {
    digitalWrite(pinWifiStatus, HIGH); // Turn on WiFi status LED
    serverTCP.begin();
    Serial.println("TCP server started");
    startRunTimeServer();
  } else {
    Serial.println("No WiFi - running without network");
  }
}

// Helper: map sensor with calibration, handle inverted calibration
float mapSensorWithCalibration(int raw, int whiteCal, int blackCal) {
  // *** SAFETY FIX: clamp raw ADC to expected range
  if (raw < 0) raw = 0;
  if (raw > 5000) raw = 5000;

  // raw range 0..4095; we want mapped 0 (white) .. 1000 (black)
  if (whiteCal == blackCal) return 0.0f; // avoid div by zero
  // If calibration is inverted (white > black) swap them
  int minC = min(whiteCal, blackCal);
  int maxC = max(whiteCal, blackCal);

  // protect calibration values
  if (minC == maxC) return 0.0f;

  // Constrain raw to calibration range then map
  int r = constrain(raw, minC, maxC);
  float mapped;
  if (whiteCal < blackCal) {
    // normal: whiteCal -> 0, blackCal -> 1000
    mapped = (float)(r - whiteCal) * 1000.0f / (float)(blackCal - whiteCal);
  } else {
    // inverted: whiteCal > blackCal
    mapped = (float)(whiteCal - r) * 1000.0f / (float)(whiteCal - blackCal);
  }
  // *** SAFETY FIX: guard NaN/Inf and clamp
  if (!isfinite(mapped)) mapped = 0.0f;
  mapped = constrain(mapped, 0.0f, 1000.0f);
  return mapped;
}

void loop() {
  unsigned long current = micros();
  // Ensure params.cycleTime has a sane minimum to avoid hogging CPU
  if (params.cycleTime < 50) params.cycleTime = 50; // 50 microseconds minimum

  if (current - previous >= params.cycleTime) {
    previous = current;

    // handle wifi clients
    dataStreaming();
    server.handleClient();
    yield(); // allow background tasks

    // Read sensors
    for (int i = 0; i < 8; ++i) {
      if (sensorPins[i] != 0) {
        // *** SAFETY FIX: protect analogRead spikes
        int raw = analogRead(sensorPins[i]);
        if (raw < 0) raw = 0;
        if (raw > 5000) raw = 5000;
        sensors[i] = raw;

        mappedSensors[i] = mapSensorWithCalibration(sensors[i], params.whiteValues[i], params.blackValues[i]);

        // *** SAFETY FIX: ensure mappedSensors valid
        if (!isfinite(mappedSensors[i])) mappedSensors[i] = 0.0f;
        mappedSensors[i] = constrain(mappedSensors[i], 0.0f, 1000.0f);
      } else {
        sensors[i] = 0;
        mappedSensors[i] = 0.0f;
      }
    }

    // calculate error
    linePosition = getLinePosition(sensors); // in mm

    // *** SAFETY FIX: catch invalid outputs
    if (!isfinite(linePosition)) linePosition = 0.0f;

    linePosition = constrain(linePosition, -33.0f, 33.0f); // limit to sensor array width
    error = linePosition;
    if (checkAllBlack(mappedSensors)){
        error = 0.0f;
        correction = 0.0f;
        Serial.println("All black detected");
    }



    // *** SAFETY FIX: guard error
    if (!isfinite(error)) error = 0.0f;
    error = constrain(error, -33.0f, 33.0f);

    // motor control PID
    if (running) forwardSpeed = params.defaultSpeed;
    else forwardSpeed = 0;

    // compute correction only when there's line (not all white)
    if (!checkAllWhite(mappedSensors)) {
      correction = pidCompute(error, params.kp, params.ki, params.kd);
      lastSeenLineTime = millis();
    } 
    else {
      // if we lost the line and running, apply a last known strategy:
      if (running) {
        if(checkAllWhite(mappedSensors)==true && correction > 0.0f) correction = 100.0f;
        if(checkAllWhite(mappedSensors)==true && correction < 0.0f) correction = -100.0f;
        // keep previous correction (or optionally set to a small search value)
      } 
      else {
        error = 0.0f;
        correction = 0.0f;
      }
    }

    // *** SAFETY FIX: guard correction
    if (!isfinite(correction)) correction = 0.0f;
    correction = constrain(correction, -1000.0f, 1000.0f);

    // if running and lost for long time, stop
    if (millis() - lastSeenLineTime > (unsigned long)params.maxTimeWithoutLine) {
      running = false;
    }

    // compute scale safely
    double denom = (double)forwardSpeed + fabs(correction);
    if (denom <= 0.0) {
      scale = 1.0;
    } else if (denom > (double)params.maxSpeed) {
      scale = (double)params.maxSpeed / denom;
    } else {
      scale = 1.0;
    }

    m1_raw = forwardSpeed + correction;
    m2_raw = forwardSpeed - correction;

    m1 = m1_raw * scale;
    m2 = m2_raw * scale;

    m1 = constrain(m1, -100.0, 100.0);
    m2 = constrain(m2, -100.0, 100.0);

    m1_pwm_fwd = m1 > 0 ? map(m1, 0, 100, 0, 255) : 0;
    m1_pwm_bwd = m1 < 0 ? map(-m1, 0, 100, 0, 255) : 0;

    m2_pwm_fwd = m2 > 0 ? map(m2, 0, 100, 0, 255) : 0;
    m2_pwm_bwd = m2 < 0 ? map(-m2, 0, 100, 0, 255) : 0; 

    // *** SAFETY FIX: ensure pwm within bounds

    analogWrite(25, m1_pwm_fwd);
    analogWrite(26, m1_pwm_bwd);
    analogWrite(27, m2_pwm_fwd);
    analogWrite(14, m2_pwm_bwd);

    calculationTime = micros() - current;
  }
}

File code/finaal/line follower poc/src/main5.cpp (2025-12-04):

#include <Arduino.h>
#include "EEPROMAnything.h"
#include <WiFi.h>
#include <WebServer.h>
#include <DNSServer.h>
#include <ESPmDNS.h>

// Control loop timing
unsigned long previous = 0;
unsigned long calculationTime = 0;

// Data streaming
uint8_t cyclesSinceLastSend = 0;
const uint8_t cyclesPerSend = 4;

unsigned long lastSeenLineTime = 1000;
unsigned long lapStartTime = 0;
unsigned long lapTime = 0;
uint8_t crossingCount = 0;
bool crossingDetected = false;

// State variables
bool running = false;
int forwardSpeed = 0;
bool motorsEnabled = false;
bool ledWifiStatus = false;

// PID variables
float error = 0.0f;
float linePosition = 0.0f;
float correction = 0.0f;
float scale = 1.0f;
float lastError = 0.0f;
float iTerm = 0.0f;

// Motor variables
int m1 = 0, m2 = 0;
uint8_t m1_pwm_fwd = 0, m1_pwm_bwd = 0;
uint8_t m2_pwm_fwd = 0, m2_pwm_bwd = 0;

// Pin definitions
const uint8_t pinWifiStatus = 42;
const uint8_t motorPins[4] = {17, 18, 45, 46}; // m1_fwd, m1_bwd, m2_fwd, m2_bwd
const uint8_t sensorPins[8] = {10, 9, 8, 7, 6, 5, 4, 2};

// Sensor data
int sensors[8] = {0};
float mappedSensors[8] = {0.0f};

// Configuration structure
struct param_t {
  unsigned long cycleTime;
  char ssid[32] ;
  char password[64] ;
  int defaultSpeed;
  float diff;
  int blackValues[8];
  int whiteValues[8];
  double kp;
  double ki;
  double kd;
  int maxTimeWithoutLine;
  int crossingsPerLap;
} params;

// WiFi objects
WebServer server(80);
DNSServer dnsServer;
WiFiServer serverTCP(1234);
WiFiClient client;

// String buffer for data streaming (reuse to avoid fragmentation)
String dataBuffer;

// Forward declarations
void setupMotors();
void readSensors();
void computePID();
void updateMotors();
void dataStreaming();

bool tryConnectWithParams(unsigned long timeoutMs = 15000) {
  if (strlen(params.ssid) == 0) return false;

  WiFi.mode(WIFI_STA);
  WiFi.setAutoReconnect(true);
  WiFi.persistent(false); // Don't wear out flash
  
  Serial.print(F("Connecting to ")); 
  Serial.println(params.ssid);
  
  WiFi.begin(params.ssid, params.password);

  unsigned long start = millis();
  while (millis() - start < timeoutMs) {
    if (WiFi.status() == WL_CONNECTED) {
      Serial.print(F("Connected with IP: "));
      Serial.println(WiFi.localIP());
      return true;
    }
    delay(200);
  }
  return false;
}

void startConfigPortal(unsigned long portalTimeoutMs = 300000UL) {
  const char* apName = "lineFollower_Wifi_Config";
  const char* apPass = "configureme";

  IPAddress apIP(192, 168, 4, 1);
  IPAddress apGateway(192, 168, 4, 1);
  IPAddress apSubnet(255, 255, 255, 0);

  WiFi.mode(WIFI_AP);
  WiFi.softAPConfig(apIP, apGateway, apSubnet);
  WiFi.softAP(apName, apPass);

  const byte DNS_PORT = 53;
  dnsServer.start(DNS_PORT, F("*"), apIP);

  server.on("/", []() {
    String page = F("<html><body>"
                  "<h2>LineFollower WiFi Setup</h2>"
                  "<form action=\"/save\" method=\"POST\">"
                  "SSID:<br><input type=\"text\" name=\"ssid\" value=\"");
    page += params.ssid;
    page += F("\"><br>Password:<br><input type=\"password\" name=\"pwd\"><br><br>"
              "<input type=\"submit\" value=\"Save\">"
              "</form></body></html>");
    server.send(200, F("text/html"), page);
  });

  server.on("/save", HTTP_POST, []() {
    if (server.hasArg(F("ssid")) && server.hasArg(F("pwd"))) {
      String ss = server.arg(F("ssid"));
      String pw = server.arg(F("pwd"));
      ss.toCharArray(params.ssid, sizeof(params.ssid));
      pw.toCharArray(params.password, sizeof(params.password));
      
      EEPROM_writeAnything(0, params);
      server.send(200, F("text/html"), F("Saved. Restarting..."));
      delay(1000);
      ESP.restart();
    } else {
      server.send(400, F("text/plain"), F("Missing fields"));
    }
  });

  server.onNotFound([]() {
    server.send(404, F("text/plain"), F("Not found"));
  });

  server.begin();

  unsigned long started = millis();
  while (millis() - started < portalTimeoutMs) {
    dnsServer.processNextRequest();
    server.handleClient();
    delay(50);
    digitalWrite(pinWifiStatus, !digitalRead(pinWifiStatus));
  }

  server.stop();
  dnsServer.stop();
  WiFi.softAPdisconnect(true);
}

void startWifi() {
  if (tryConnectWithParams()) return;
  
  Serial.println(F("Starting config portal..."));
  startConfigPortal();
}

void dataStreaming() {
  if (!client || !client.connected()) {
    client = serverTCP.available();
  }

  if (++cyclesSinceLastSend < cyclesPerSend) return;
  cyclesSinceLastSend = 0;

  if (!client || !client.connected()) return;

  // Build JSON efficiently
  dataBuffer = "{\"timeStamp\":";
  dataBuffer += millis();
  dataBuffer += F(",\"ssid\":\"");
  dataBuffer += params.ssid;
  dataBuffer += F("\",\"cycleTime\":");
  dataBuffer += params.cycleTime;
  dataBuffer += F(",\"calculationTime\":");
  dataBuffer += calculationTime;
  dataBuffer += F(",\"running\":");
  dataBuffer += running;
  dataBuffer += F(",\"motorsEnabled\":");
  dataBuffer += motorsEnabled;
  dataBuffer += F(",\"kp\":");
  dataBuffer += params.kp;
  
  float cycleTimeInSec = params.cycleTime * 0.000001f;
  dataBuffer += F(",\"ki\":");
  dataBuffer += (params.ki / cycleTimeInSec);
  dataBuffer += F(",\"kd\":");
  dataBuffer += (params.kd * cycleTimeInSec);
  dataBuffer += F(",\"linePosition\":");
  dataBuffer += linePosition;
  dataBuffer += F(",\"error\":");
  dataBuffer += error;
  dataBuffer += F(",\"correction\":");
  dataBuffer += correction;
  dataBuffer += F(",\"motor1\":");
  dataBuffer += m1;
  dataBuffer += F(",\"motor2\":");
  dataBuffer += m2;
  dataBuffer += F(",\"defaultSpeed\":");
  dataBuffer += params.defaultSpeed;
  dataBuffer += F(",\"diff\":");
  dataBuffer += params.diff;
  dataBuffer += F(",\"maxTimeWithoutLine\":");
  dataBuffer += params.maxTimeWithoutLine;
  dataBuffer += F(",\"crossingsPerLap\":");
  dataBuffer += params.crossingsPerLap;
  dataBuffer += F(",\"lapTime\":");
  dataBuffer += lapTime;
  dataBuffer += F(",\"crossingCount\":");
  dataBuffer += crossingCount;
  
  // Arrays
  dataBuffer += F(",\"rawSensors\":[");
  for (uint8_t i = 0; i < 8; i++) {
    dataBuffer += sensors[i];
    if (i < 7) dataBuffer += ',';
  }
  
  dataBuffer += F("],\"sensors\":[");
  for (uint8_t i = 0; i < 8; i++) {
    dataBuffer += mappedSensors[i];
    if (i < 7) dataBuffer += ',';
  }
  
  dataBuffer += F("],\"blackValues\":[");
  for (uint8_t i = 0; i < 8; i++) {
    dataBuffer += params.blackValues[i];
    if (i < 7) dataBuffer += ',';
  }
  
  dataBuffer += F("],\"whiteValues\":[");
  for (uint8_t i = 0; i < 8; i++) {
    dataBuffer += params.whiteValues[i];
    if (i < 7) dataBuffer += ',';
  }
  
  dataBuffer += F("]}");
  
  client.println(dataBuffer);
}
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

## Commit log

2025-10-17 electrische tekeningen
    [10102025.kicad_pcb, 10102025.kicad_sch, planA.kicad_pcb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]
2025-10-17 gui3 and module1 fix
    [module1.py]
2025-10-17 button added
2025-10-30 begin cad ontwerp
    [DRV8833.IGS, DRV8833.SLDPRT, DRV8833.STEP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]
2025-10-30 begin pcb
    [planA.kicad_pcb, planA.kicad_sch, planB.SLDASM]
2025-12-04 Update distance sensor and speed details in readme
